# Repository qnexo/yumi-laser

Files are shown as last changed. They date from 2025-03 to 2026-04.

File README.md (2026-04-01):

<div align="center">

# Yumi Laser - Documentation Complète

&nbsp;
&nbsp;
&nbsp;
&nbsp;
&nbsp;

&nbsp;
&nbsp;
&nbsp;


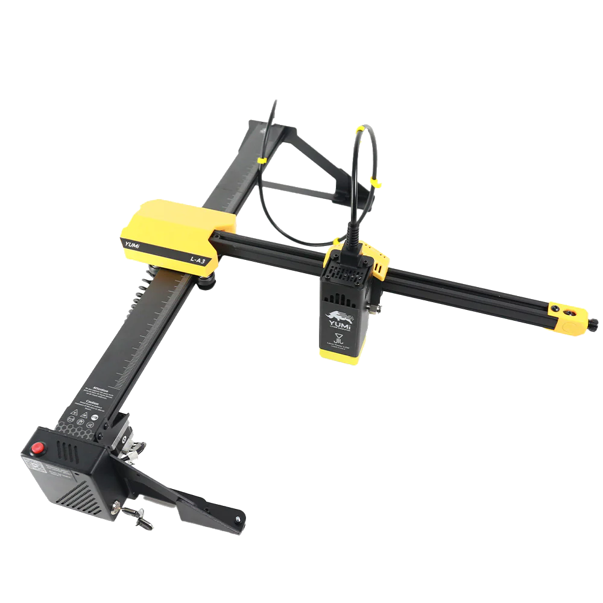
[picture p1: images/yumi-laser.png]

</div>

Bienvenue dans **le dépôt de référence pour modifier, améliorer et dompter le YUMI L-A**.  
Tu veux flasher un firmware propre, ajouter des capteurs de fin de course, activer le Wi-Fi sans écran, ou même modéliser des pièces pour ta machine ? 

T’es au bon endroit.

---

## 🚀 Objectif du projet

Ce dépôt regroupe **tout le nécessaire pour transformer ton YUMI L-A2** en une machine stable, modulaire et digne de projets sérieux.  
On parle ici de modifications concrètes testées IRL, pas de théories de forum.

---

## 📚 Sommaire
- [🛠️ Installation et Montage](https://github.com/qnexo/yumi-laser/blob/main/docs/yumi-laser-l-a4-a3-montage.pdf)
- [🚀 Firmware](#firmware)
- [📶 Configuration WiFi](#configuration-wifi)
- [📐 Logiciel LightBurn](https://lightburnsoftware.com/)
- [⚠️ Consignes de sécurité](#consignes-de-sécurité)
- [🛎️ Assistance et support](#assistance-et-support)
- [📜 Licence](#licence)

---

## 🧰 Contenu du dépôt

📁 firmware/ → Firmware GRBL modifié (capteurs, Wi-Fi, configs YUMI)

📁 hardware/ → STL/STEP, plans de montage, upgrades mécaniques

📁 docs/ → Fiches techniques et manuels PDF

📁 modifications/ → Étapes pas-à-pas pour les hacks (photos, branchements, etc.)

📁 tools/ → Scripts et utilitaires de flash/test

---

## 🛠️ Modifications principales

- ✅ Activation des **capteurs de fin de course**
- ✅ Activation du **Wi-Fi sans écran**
- ✅ Modification de la configuration GRBL pour laser YUMI
- ✅ Intégration de pièces imprimables (ventilateurs, support module, etc.)
- 🚧 [À venir] Ajout d’un relais de sécurité / arrêt d’urgence

---

## ⚙️ Installer le firmware

> 🔥 **Important** : Sauvegarde ton firmware d’origine si tu veux pouvoir revenir en arrière.

1. Branche ton YUMI via USB
2. Ouvre `tools/flasher.bat` *(ou utilise `avrdude` si tu préfères la ligne de commande)*
3. Flash le fichier `.hex` adapté à ta config depuis `firmware/`
4. Redémarre, connecte avec un terminal série (115200 baud)
5. Tape `$$` pour vérifier les réglages

---

## 🔌 Branchement des capteurs (Endstops)

**Type** : capteur mécanique Normally Open (NO)  
**Connexion** :
- X min → pin D9
- Y min → pin D10  
(Peut varier selon le modèle de carte – voir `docs/yumi-board-pinout.pdf`)

📸 *Voir photos dans `modifications/endstop-photos/`*

---

## 📷 Aperçus

YUMI Modifié  
*Vue avant avec support capteurs et module laser 10W*

---

## 📬 Contact & communauté

👉 Groupe WhatsApp : [**lien à insérer**]  
📧 Contact : qnexo.dev@gmail.com *(ou autre mail/profil si tu préfères)*

---

## ❤️ Contribuer

Les PR sont bienvenues. Merci de :
- Forker ce dépôt
- Travailler sur une branche dédiée
- Proposer une modif claire avec explication

---

## 🧠 À faire (Roadmap)

- [ ] Ajout d’un support écran TFT
- [ ] Ajout d’un système d’extraction d’air imprimable
- [ ] Création d’un profil LightBurn optimisé
- [ ] Documentation FR/EN parallèle

---

**Hack the machine. Dompte la lumière. 🔥**

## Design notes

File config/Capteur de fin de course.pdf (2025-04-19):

# Capteur de fin de course

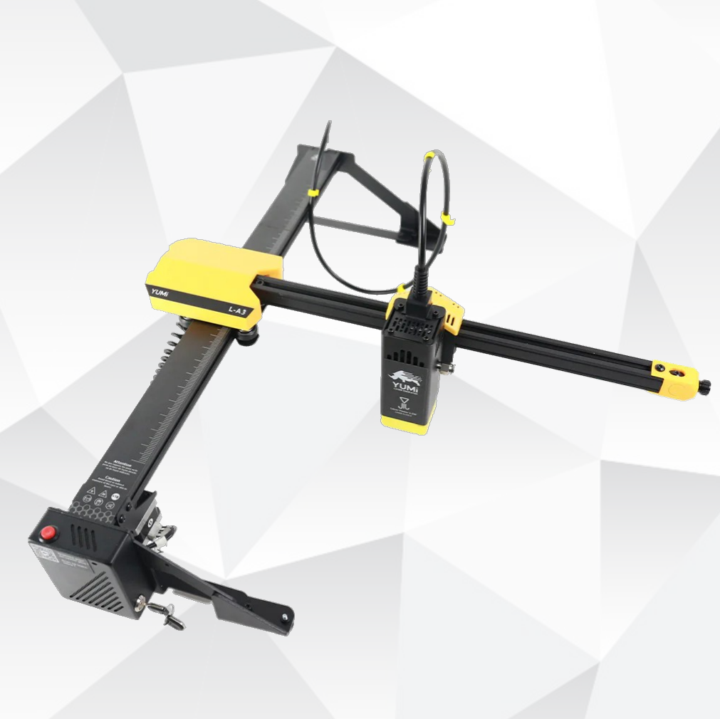
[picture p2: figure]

### Sommaire

1. Présentation du projet.
2. Matériel nécessaire.
3. Installation physique des capteurs.
4. Paramétrage dans LightBurn.
5. Réglages GRBL (copier-coller).
6. Vérification et tests.
7. Problèmes fréquents et solutions.
8. Notes personnelles.

### 1. Présentation du projet

L'ajout de capteurs permet de définir une origine fiable. Cela permet de bénéficier de la fonction Autoguider et d’éviter les dépassements de zone de travail.

### 2. Matériel nécessaire

- Laser Yumi L-A4/3/2
- Capteurs NO (normalement ouverts)
- Fils Dupont / connecteurs
- Logiciel LightBurn
- Pour ce montage, nous allons utiliser des capteurs GTIWUNG à butée mécanique, avec câble inclus.
On peut les trouver sur Amazon pour environ 9 €.
- N'oubliez pas de télécharger les fichiers STL pour les supports des capteurs.
Nous avons également d'autres modèles de fichiers STL, que ce soit à clips ou à visser, selon vos préférences.

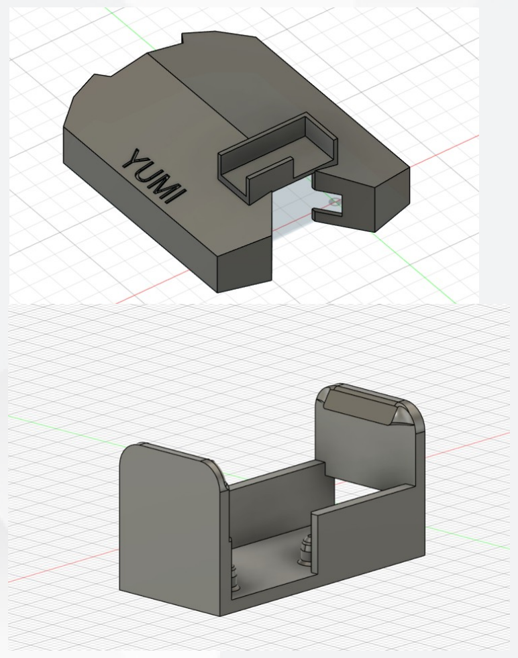
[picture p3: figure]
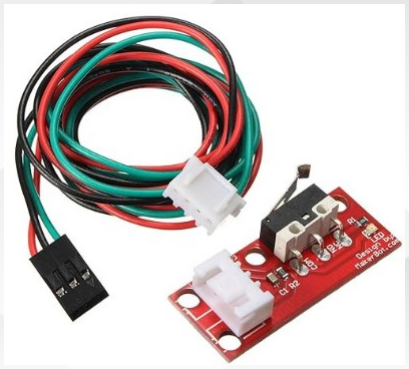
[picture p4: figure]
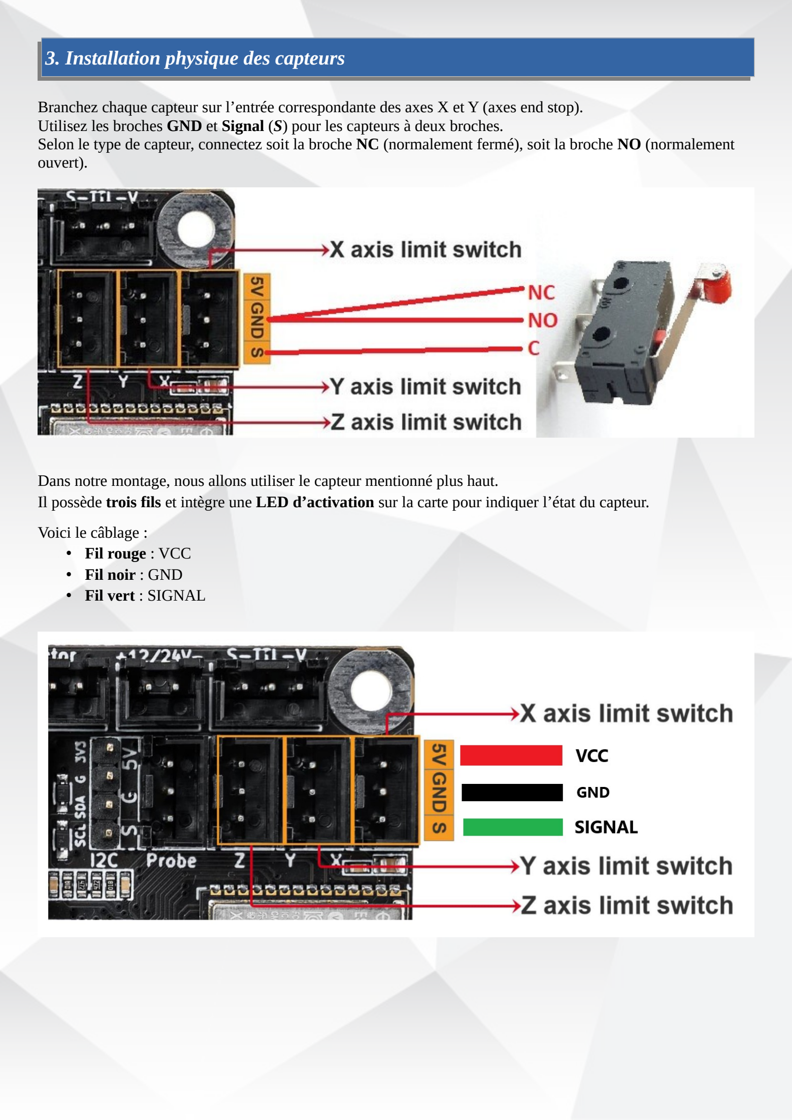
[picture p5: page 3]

### 3. Installation physique des capteurs

Branchez chaque capteur sur l’entrée correspondante des axes X et Y (axes end stop).
Utilisez les broches GND et Signal (S) pour les capteurs à deux broches.
Selon le type de capteur, connectez soit la broche NC (normalement fermé), soit la broche NO (normalement ouvert).

Dans notre montage, nous allons utiliser le capteur mentionné plus haut.
Il possède trois fils et intègre une LED d’activation sur la carte pour indiquer l’état du capteur. Voici le câblage :
- Fil rouge : VCC
- Fil noir : GND
- Fil vert : SIGNAL

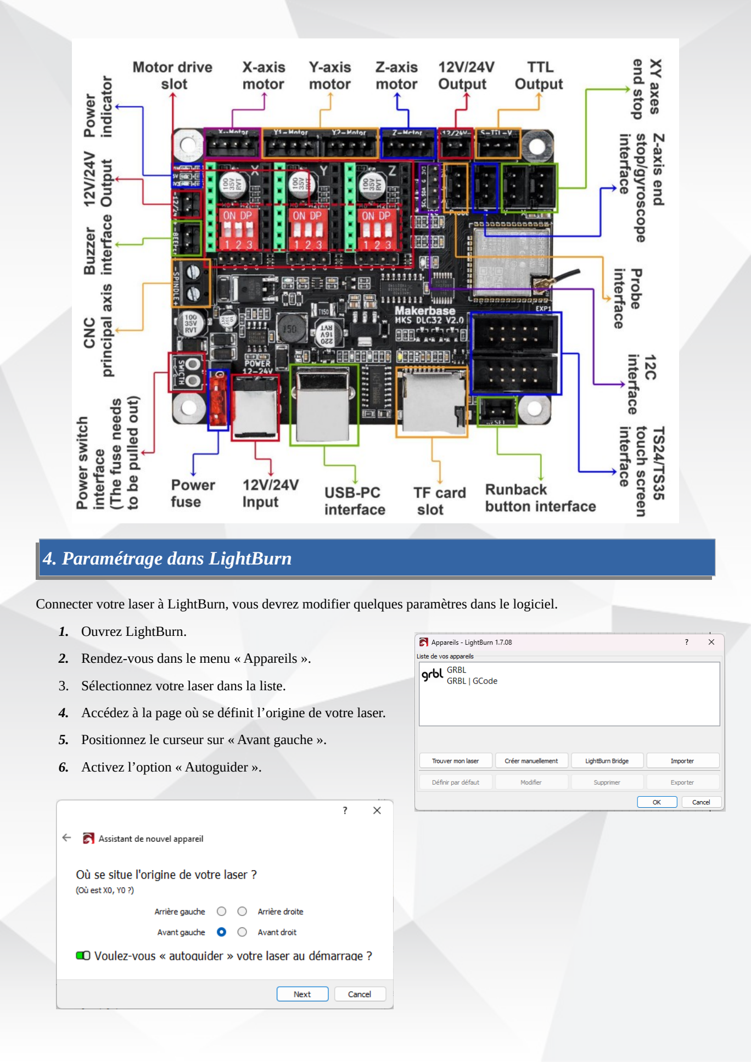
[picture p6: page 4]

### 4. Paramétrage dans LightBurn

Connecter votre laser à LightBurn, vous devrez modifier quelques paramètres dans le logiciel.

1. Ouvrez LightBurn.
2. Rendez-vous dans le menu « Appareils ».
3. Sélectionnez votre laser dans la liste.
4. Accédez à la page où se définit l’origine de votre laser.
5. Positionnez le curseur sur « Avant gauche ».
6. Activez l’option « Autoguider ».

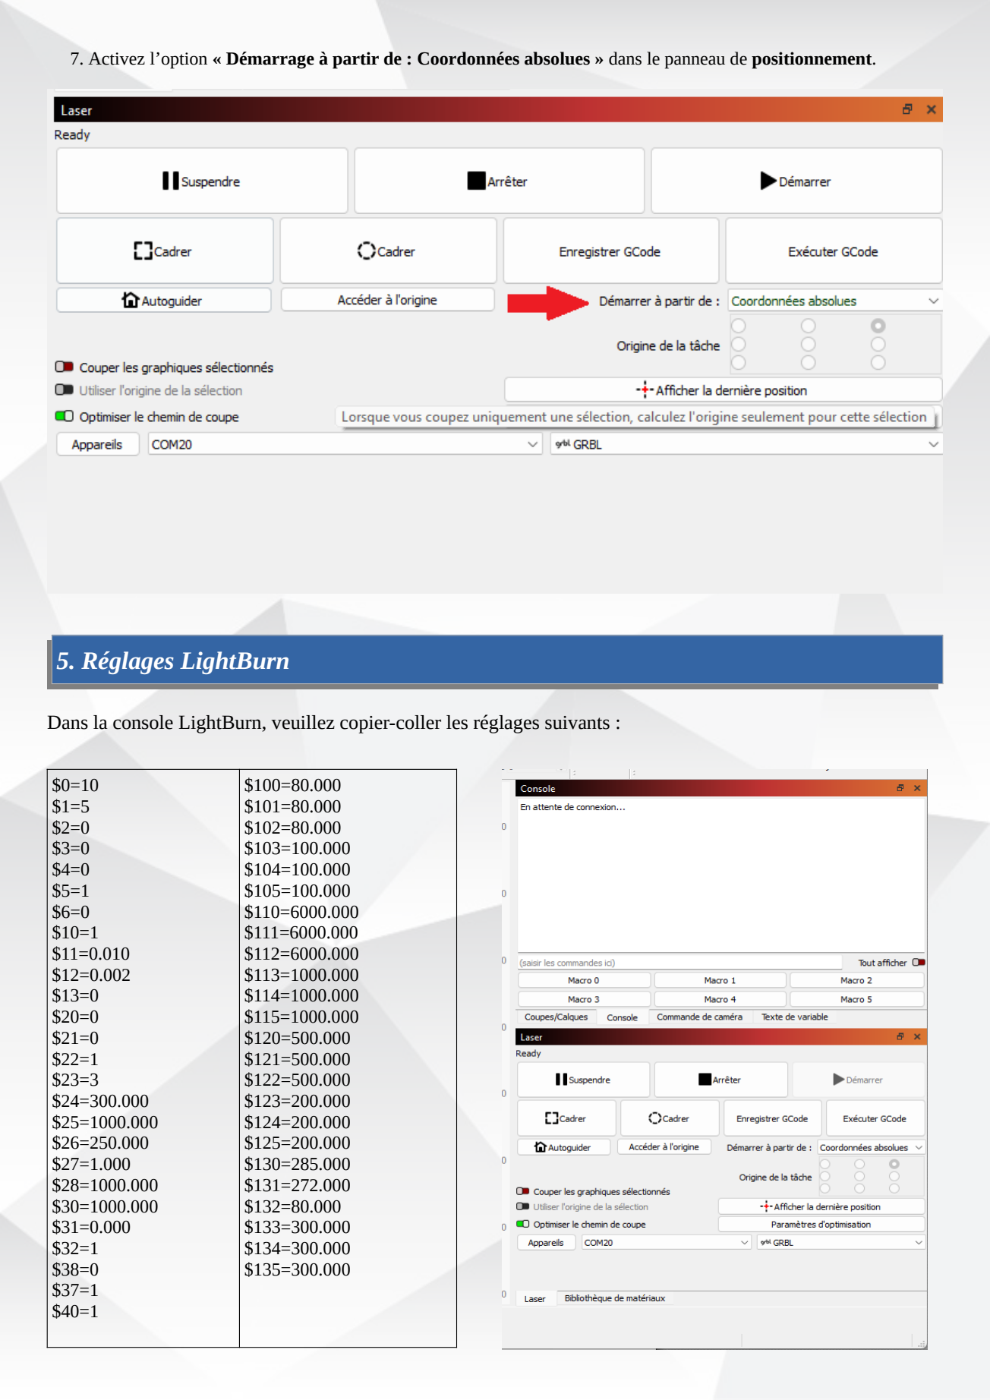
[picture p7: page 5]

7. Activez l’option « Démarrage à partir de : Coordonnées absolues » dans le panneau de positionnement.

### 5. Réglages LightBurn

Dans la console LightBurn, veuillez copier-coller les réglages suivants :

$0=10
$1=5
$2=0
$3=0
$4=0
$5=1
$6=0
$10=1
$11=0.010
$12=0.002
$13=0
$20=0
$21=0
$22=1
$23=3
$24=300.000
$25=1000.000
$26=250.000
$27=1.000
$28=1000.000
$30=1000.000
$31=0.000
$32=1
$38=0
$37=1
$40=1

$100=80.000
$101=80.000
$102=80.000
$103=100.000
$104=100.000
$105=100.000
$110=6000.000
$111=6000.000
$112=6000.000
$113=1000.000
$114=1000.000
$115=1000.000
$120=500.000
$121=500.000
$122=500.000
$123=200.000
$124=200.000
$125=200.000
$130=285.000
$131=272.000
$132=80.000
$133=300.000
$134=300.000
$135=300.000

### Paramètres – Détail et Fonction

Paramètre | Description | Valeur
$0 | Délai avant désactivation des moteurs | 10 ms
$1 | Délai de repos des moteurs | 5 ms
$2 | Inversion des signaux de pas | 0
$3 | Inversion des directions de moteur | 0
$4 | Inversion du signal d’activation des moteurs | 0
$5 | Inversion des signaux de fin de course | 1 (inversé)
$6 | Inversion du signal de la sonde (probe) | 0
$10 | Rapport d'état - masque de bits | 1
$11 | Déviation de jonction (fluidité des virages) | 0.010 mm
$12 | Tolérance des arcs (précision) | 0.002 mm
$13 | Unités en pouces (0 = mm, 1 = pouces) | 0 (mm)
$20 | Limites logicielles activées | 0 (désactivé)
$21 | Limites matérielles activées | 0 (désactivé)
$22 | Cycle de référencement (homing) activé | 1 (activé)
$23 | Inversion des directions du homing | 3
$24 | Vitesse de recherche du homing | 300 mm/min
$25 | Vitesse d’approche du homing | 1000 mm/min
$26 | Temps de rebond pour homing | 250 ms
$27 | Retrait après homing | 1 mm
$28 | Vitesse de retour G28 | 1000 mm/min
$30 | Vitesse maximale de la broche (ou laser) | 1000
$31 | Vitesse minimale de la broche (ou laser) | 0
$32 | Mode laser activé | 1 (activé)
$38 | Sonde activée | 0 (désactivé)
$37 | Accessoires activés | 1 (activé)
$40 | Désactivation automatique des moteurs | 1 (activé)
$100 | Pas/mm pour l’axe X | 80
$101 | Pas/mm pour l’axe Y | 80
$102 | Pas/mm pour l’axe Z | 80
$103 | Pas/mm pour l’axe A | 100
$104 | Pas/mm pour l’axe B | 100
$105 | Pas/mm pour l’axe C | 100
$110 | Vitesse max de l’axe X | 6000 mm/min
$111 | Vitesse max de l’axe Y | 6000 mm/min
$112 | Vitesse max de l’axe Z | 6000 mm/min

$113 | Vitesse max de l’axe A | 1000 mm/min
$114 | Vitesse max de l’axe B | 1000 mm/min
$115 | Vitesse max de l’axe C | 1000 mm/min
$120 | Accélération de l’axe X | 500 mm/s²
$121 | Accélération de l’axe Y | 500 mm/s²
$122 | Accélération de l’axe Z | 500 mm/s²
$123 | Accélération de l’axe A | 200 mm/s²
$124 | Accélération de l’axe B | 200 mm/s²
$125 | Accélération de l’axe C | 200 mm/s²
$130 | Course maximale de l’axe X | 285 mm
$131 | Course maximale de l’axe Y | 272 mm
$132 | Course maximale de l’axe Z | 80 mm
$133 | Course maximale de l’axe A | 300 mm
$134 | Course maximale de l’axe B | 300 mm
$135 | Course maximale de l’axe C | 300 mm

### 6. Vérification et tests

1. Connecter le laser via USB.
2. L’autoguidage doit se faire automatiquement.
3. Si ce n’est pas le cas, veuillez le faire manuellement en cliquant sur « Autoguider ».
4. Observer le comportement : arrêt correct sur les capteurs.
5. Corriger le placement du capteur si les fins de course ne réagissent pas.

### 7. Problèmes fréquents et solutions

Problème | Symptôme | Cause probable | Solution
Capteur ne réagit pas. | Laser ne s'arrête pas contrôle le capteur | Branchement incorrect. Capteur défectueux. | Vérifier câblage GND et S. Remplacement capteur NO.
Pas de mouvement Autoguider | Rien ne se passe | $22=1 non actif | Activer $22=1 et vérifier LED capteur
Origine incorrecte | Se place en haut | $23 incorrect | Mettre $23=1
LED toujours allumée | Toujours actif | Capteur défectueux ou NC | Tester en NO ou changer capteur
Erreur GRBL | Pas de connexion | Port ou vitesse incorrecte | Changement de port. Remplacement du câble USB.
Câblage chauffe | Reste machine | Court-circuit | Vérifier polarité et isoler câbles

Problème | Symptôme | Cause probable | Solution
Gravure faible ou inégale | Le laser grave faiblement ou par à-coups | Mauvaise mise au point ou lentille sale | Nettoyer la lentille, refaire la mise au point
Laser ne s’allume pas | Aucune émission laser pendant la gravure carte-mère allumé | Alimentation, mauvais câblage PWM ou $32=0 | Vérifier câblage, tester en manuel (M3 S100) et vérifier $$ voir $32 sur 1
Décalage des gravures | Le dessin est décalé ou en escalier | Poulie desserrée, courroie lâche, vitesse trop élevée | Resserrer, ajuster la tension des courroies, réduire la vitesse
Gravure en miroir | L’image est inversée | Origine mal définie, $3 mal configuré | Essayer différentes valeurs de $3 (inversion de directions moteurs)
Le Autoguider ne fonctionne pas | L’axe se déplace dans le mauvais sen | Mauvais sens moteur ou mauvais branchement capteur | Inverser sens moteur via $3, vérifier connexion des capteurs
L’axe cogne ou vibre | Mouvement irrégulier ou bruit anormal | Tension moteur incorrecte, mauvaise configuration | Vérifier les pilotes, ajuster le courant, vérifier le micro-stepping
Job s’arrête au milieu | Gravure arrêtée sans message d’erreur | Perte de communication, mauvaise alimentation | Changer câble USB, utiliser alimentation stable, désactiver l’économiseur USB
Assist toujours active | Pompe tourne en continu | Branchée en direct ou mauvaise config pin | Vérifier branchement, désactiver Air Assist dans LightBurn, envoyer M9
Carte ne démarre pas du tout | Aucun signe de vie, même pas d’écran | Alimentation, Contacteur à clé HS ou inactif | Remplacer le contacteur ou le retirer (pont direct) Vérifier alim 12/24V
Gravure se fait au mauvais endroit | Décalage par rapport au visuel dans LightBurn | Origine mal placée, mode de départ incorrect | Vérifier position d’origine et mode Start from (User origin, etc.)
Laser ne s’éteint pas après un job | Reste allumé à faible puissance | Mode laser mal géré ou M5 non envoyé | Ajouter M5 à la fin, vérifier $32=1 pour laser mode
Gravure irrégulière sur les bords | Bords flous ou trop puissants | Mauvais réglage d’accélération / vitesse | Réduire accélération ($120/$121) ou la vitesse
Le job s’exécute à l’envers | Gravure retournée horizontalement ou verticalement | Mauvaise configuration de $3 ou de l’origine | Tester les 4 combinaisons possibles de $3 (de 0 à 7) câble Y au mauvais endroit
Connexion instable via WiFi | Déconnexion fréquente ou lenteur | Mauvaise réception du WiFi | Réduire distance au routeur, privilégier wifi 2.5GHz stable, privilégier USB,
Gravure en “pointillés” | Le laser clignote ou ne reste pas constant | Mauvaise masse, mauvais câblage TTL ou problème GND | Vérifier GND commun entre laser et carte, resserrer connexions

### 8. Notes personnelles

Espace libre pour remarques et réglages spécifiques : _________________________________________________________________________________________ _________________________________________________________________________________________ _________________________________________________________________________________________ _________________________________________________________________________________________ _________________________________________________________________________________________ _________________________________________________________________________________________ _________________________________________________________________________________________ _________________________________________________________________________________________ _________________________________________________________________________________________ _________________________________________________________________________________________ _________________________________________________________________________________________ _________________________________________________________________________________________ _________________________________________________________________________________________ _________________________________________________________________________________________ _________________________________________________________________________________________ _________________________________________________________________________________________ _________________________________________________________________________________________ _________________________________________________________________________________________ _________________________________________________________________________________________ _________________________________________________________________________________________ _________________________________________________________________________________________ _________________________________________________________________________________________ _________________________________________________________________________________________ _________________________________________________________________________________________ _________________________________________________________________________________________ _________________________________________________________________________________________ _________________________________________________________________________________________ _________________________________________________________________________________________ _________________________________________________________________________________________ _________________________________________________________________________________________ _________________________________________________________________________________________ _________________________________________________________________________________________ _________________________________________________________________________________________ _________________________________________________________________________________________ _________________________________________________________________________________________ _________________________________________________________________________________________ _________________________________________________________________________________________ _________________________________________________________________________________________ _________________________________________________________________________________________ _________________________________________________________________________________________ _________________________________________________________________________________________ _________________________________________________________________________________________ _________________________________________________________________________________________ _________________________________________________________________________________________

## 📘 À propos de ce PDF

Ce document a été entièrement réalisé par mes soins, en m’appuyant sur la documentation officielle de LightBurn et de Makerbase.
🙏 Un grand merci à Cupidon3D pour son aide précieuse tout au long de la configuration, ainsi que pour la mise à disposition de ses fichiers STL disponible sur le github.

🔗 Sources utiles :

📌 Documentation LightBurn (version 1.7) :
LightBurn PDF
📌 Documentation Makerbase (MKS DLC32) : Makerbase GitHub

### ⚠️ Clause de non-responsabilité

Ce document est fourni à titre informatif.
Toute modification apportée à votre matériel ou logiciel suite à ce tutoriel est réalisée à vos propres risques.
Ni l’auteur de ce document, ni les marques citées (Yumi, Makerbase, LightBurn) ne peuvent être tenus responsables des dommages matériels ou erreurs de configuration causés par une mauvaise manipulation ou un usage inadapté.

Document réalisé pour les utilisateurs du laser YUMI L-A4/3/2 ou de cartes MKS DLC32 V2,1 ✍️Par qnexo / coco

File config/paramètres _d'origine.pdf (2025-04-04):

## Paramètres de Configuration - MKS DLC32

Paramètre | Valeur | Description
DLC_TEST | 0 | Mode d'utilisation normal (0), pas le mode test (1)
$0 | 10 | Délai d'inactivité avant désactivation moteur (ms)
$1 | 5 | Temps de maintien moteur après désactivation
$2 | 0 | Inversion direction des axes (bitmask)
$3 | 0 | Sens des axes (bitmask pour homing)
$4 | 0 | Pas/inversion pour drivers
$5 | 1 | Inversion signal de fin de course X
$6 | 0 | Inversion du signal de la sonde
$10 | 1 | Rapports de position machine uniquement
$11 | 0.010 | Précision du planage (mm)
$12 | 0.002 | Précision des arcs
$13 | 0 | Unités (0 = mm, 1 = pouces)
$20 | 0 | Limite logicielle désactivée
$21 | 0 | Fins de course désactivées
$22 | 0 | Homing désactivé
$23 | 1 | Direction du homing (X inversé, Y normal)
$24 | 300.000 | Vitesse lente du homing (mm/min)
$25 | 1000.000 | Vitesse rapide du homing (mm/min)
$26 | 250.000 | Délais de rebond capteurs (debounce)
$27 | 1.000 | Retrait après déclenchement capteur
$28 | 1000.000 | Paramètre interne (MKS)
$30 | 1000.000 | Puissance maximale PWM du laser
$31 | 0.000 | Puissance minimale PWM du laser
$32 | 1 | Mode laser activé

$37 | 1 | Retour à lorigine après tâche
$38 | 1 | Détection de fin de course active (MKS)
$40 | 0 | Mode CNC activé
$100 | 80.000 | Steps/mm axe X
$101 | 80.000 | Steps/mm axe Y
$102 | 80.000 | Steps/mm axe Z
$103 | 100.000 | Steps/mm axe U
$104 | 100.000 | Steps/mm axe V
$105 | 100.000 | Steps/mm axe W
$110 | 6000.000 | Vitesse max axe X (mm/min)
$111 | 6000.000 | Vitesse max axe Y
$112 | 6000.000 | Vitesse max axe Z
$113 | 1000.000 | Vitesse max axe U
$114 | 1000.000 | Vitesse max axe V
$115 | 1000.000 | Vitesse max axe W
$120 | 500.000 | Accélération axe X (mm/s²)
$121 | 500.000 | Accélération axe Y
$122 | 500.000 | Accélération axe Z
$123 | 200.000 | Accélération axe U
$124 | 200.000 | Accélération axe V
$125 | 200.000 | Accélération axe W
$130 | 285.000 | Taille axe X (mm)
$131 | 272.000 | Taille axe Y
$132 | 80.000 | Taille axe Z
$133 | 300.000 | Taille axe U
$134 | 300.000 | Taille axe V

$135 | 300.000 | Taille axe W
[ESP110] | STA | Mode station activé (connexion à un réseau existant)
[ESP131] | 8080 | Port réseau utilisé pour la connexion TCP/IP
[ESP100] | SSID | Nom du réseau WiFi (SSID) utilisé en mode STA
[ESP101] | Password | Mot de passe WiFi utilisé pour la connexion STA

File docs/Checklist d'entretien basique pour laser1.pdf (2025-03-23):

## 🛠️ Checklist d'entretien basique pour laser :

✅ Avant chaque utilisation :
- Inspection visuelle rapide :
- Vérifie l'état des câbles et des connexions.
- Vérifie que les lentilles du laser soient propres.
- Nettoyage des lentilles :
- Utilise un chiffon microfibre et de l'alcool isopropylique.
- Nettoie délicatement pour éliminer poussière et fumée.

✅ Toutes les 10 à 20 heures d'utilisation :
- Nettoyage approfondi du module laser :
- Retire la poussière accumulée à l'aide d'une soufflette à air comprimé.
- Contrôle des axes et rails :
- Nettoie les rails avec un chiffon sec.
- Vérifie qu'il n'y a aucun résidu de matière sur les axes.
- Lubrification des rails et roulements :
- Applique une fine couche de lubrifiant à base de silicone sur les rails linéaires et les roulements pour garantir un mouvement fluide.
- Contrôle des courroies :
- Vérifie la tension des courroies, ajuste-les si nécessaire (tension modérée, ni trop serrées ni lâches).

1/2

✅ Tous les 3 mois (ou environ 50 heures d'utilisation) :
- Vérification approfondie des câbles et connecteurs :
- Inspecte soigneusement les connexions électriques.
- Remplace tout câble abîmé ou suspect.
- Inspection et nettoyage de la carte électronique (MKS DLC32) :
- Éteins et débranche le laser.
- Inspecte visuellement la carte pour détecter tout signe d'usure, de court-circuit ou poussière excessive.
- Nettoie doucement avec une soufflette ou un pinceau antistatique.

✅ Tous les 6 mois (ou 100 heures d'utilisation) :
- Contrôle général de sécurité :
- Vérifie l'intégrité physique du châssis et des protections mécaniques.
- Remplace tout élément endommagé pour garantir la sécurité d'utilisation.
- Mise à jour éventuelle du firmware :
- Vérifie si une mise à jour officielle du firmware est disponible.
- Fais une sauvegarde de ta configuration actuelle avant toute mise à jour.

## Précautions générales à suivre :

- Éteins toujours le laser avant tout entretien.
- Évite tout contact direct avec la lentille du laser à mains nues.
- Garde un environnement de travail propre et organisé.
- Utilise toujours des équipements de protection individuelle (lunettes, gants).

2/2

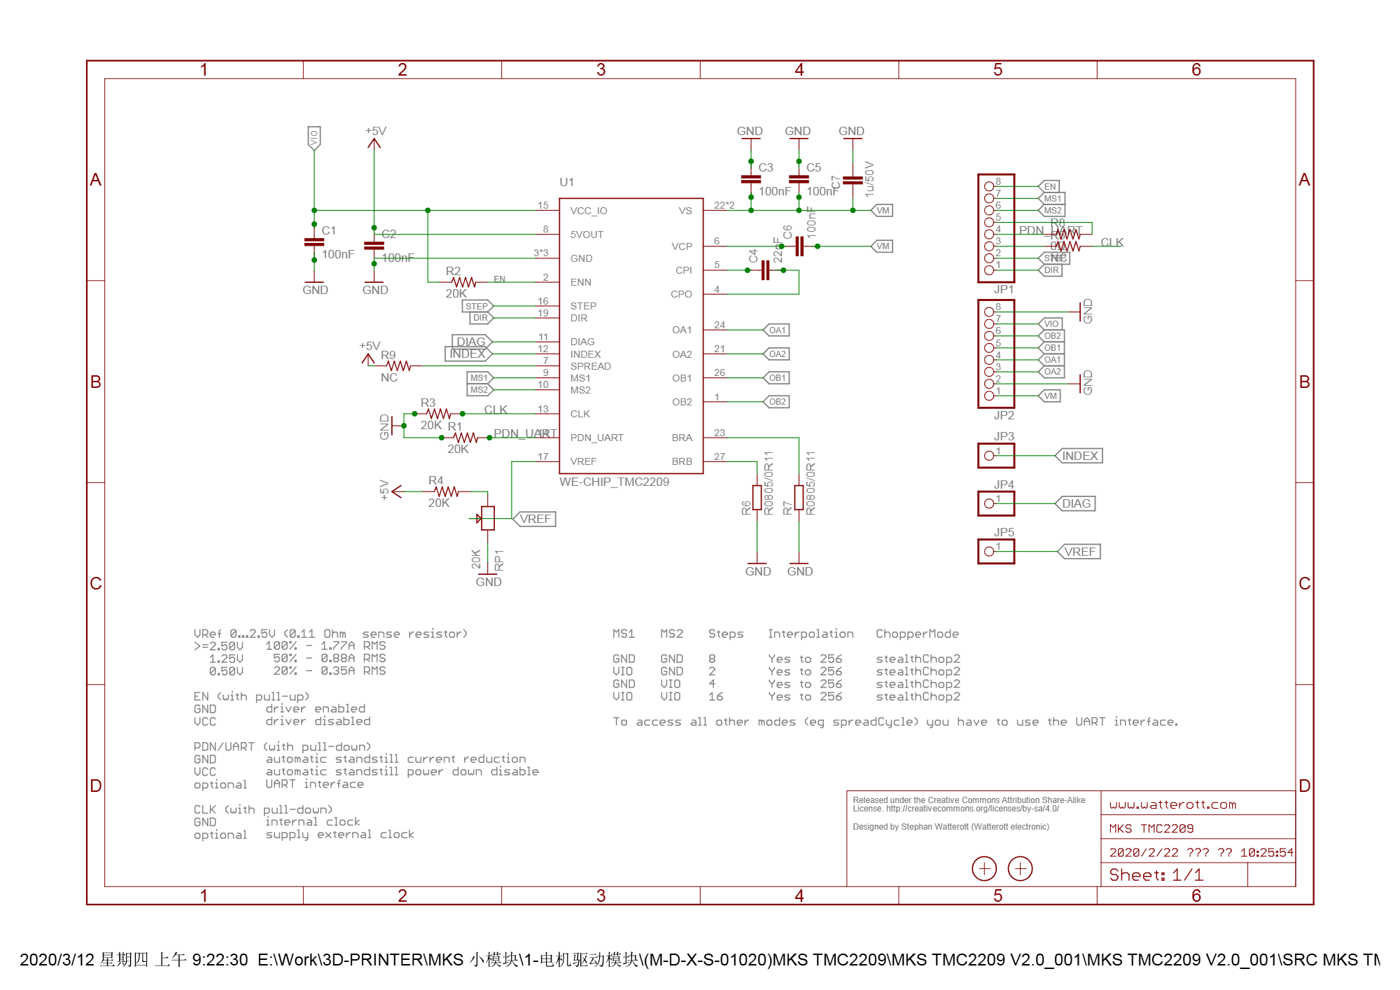
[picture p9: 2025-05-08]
images/tmc.png

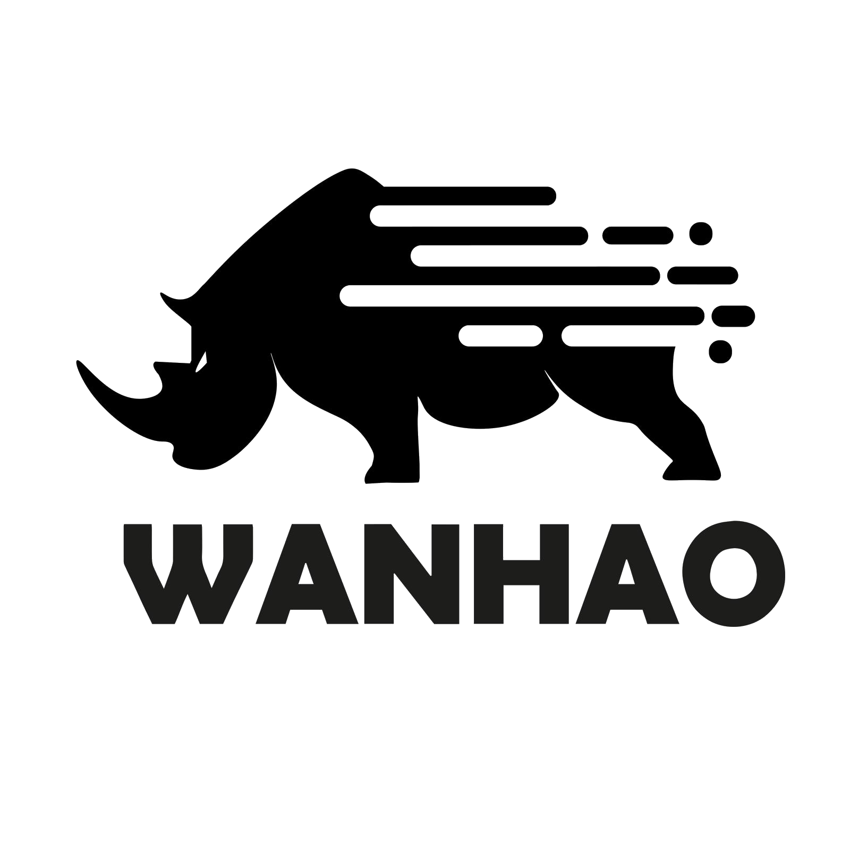
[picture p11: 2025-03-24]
images/wanhao.png

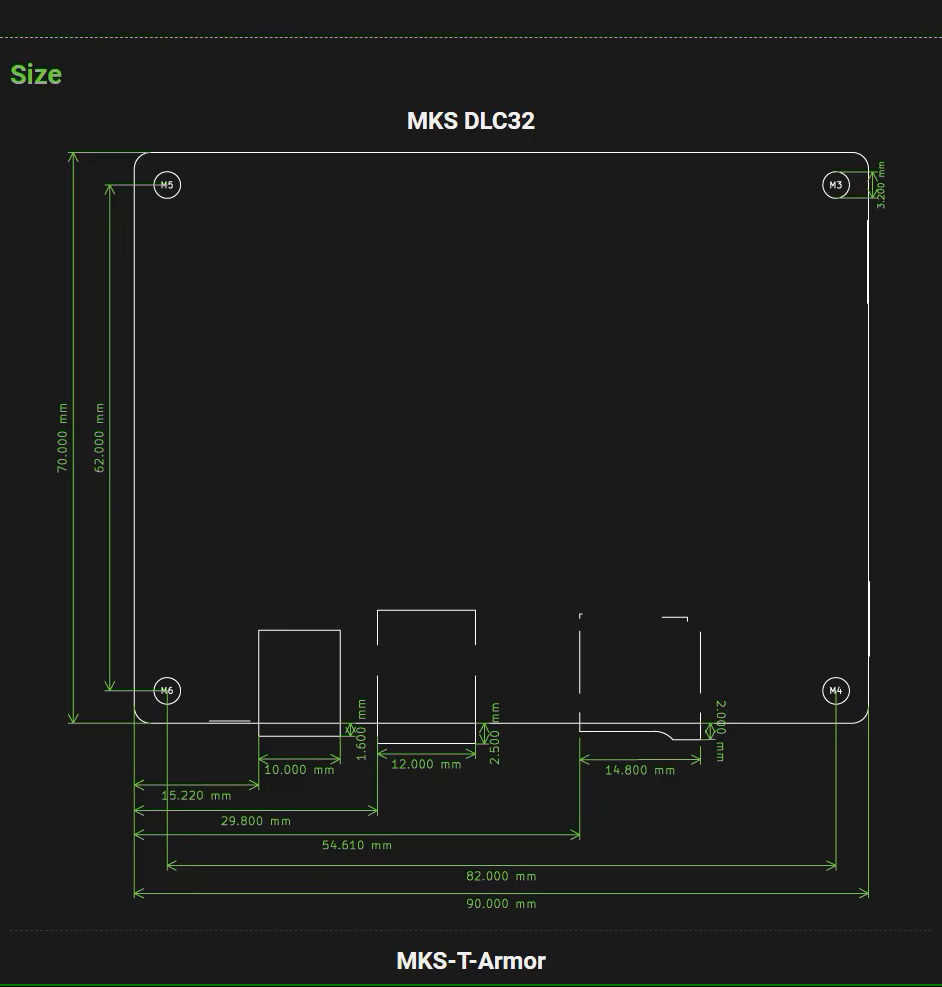
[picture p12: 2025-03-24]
images/S42874fc903dd443fb5ebef1ba6c39d80R.png

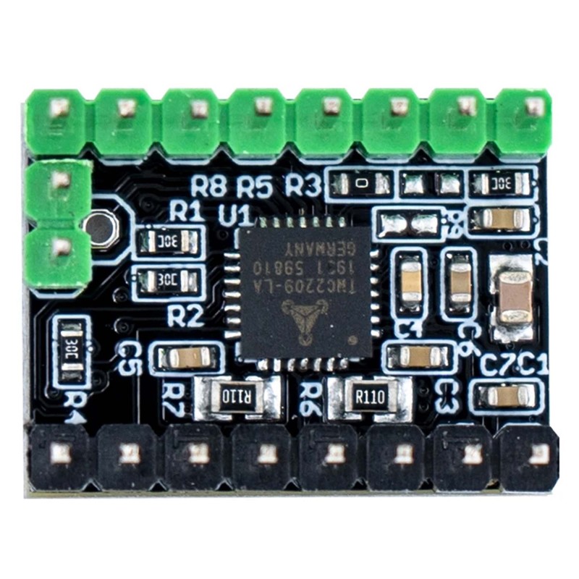
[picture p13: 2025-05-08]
images/driver-pilote-de-moteur-pas-a-pas-tmc2209.jpg

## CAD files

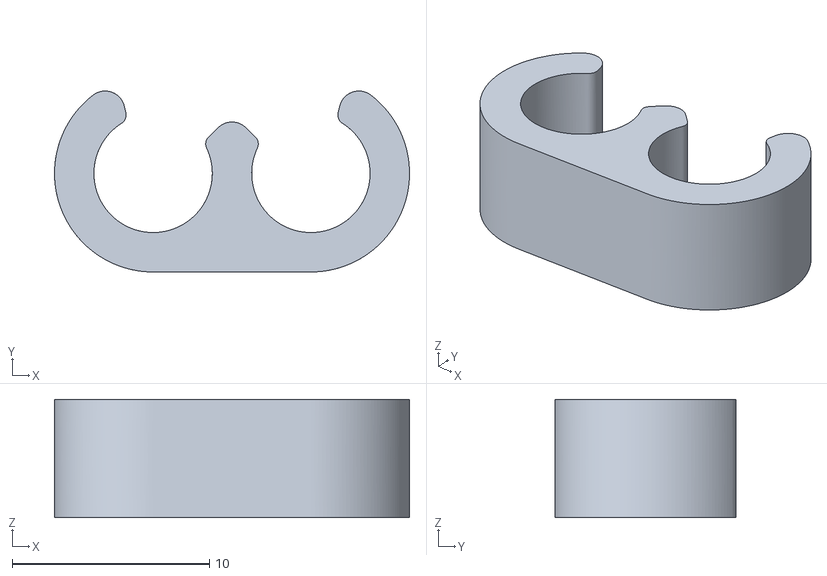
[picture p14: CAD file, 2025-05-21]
stl/clipse d'origine.stl
18.0 x 9.18 x 6.00

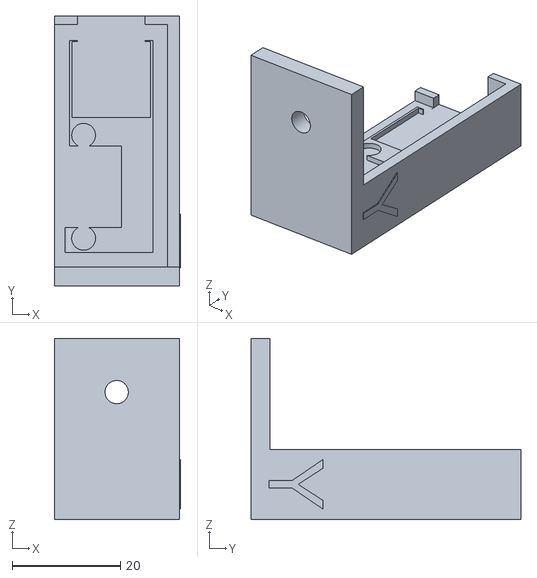
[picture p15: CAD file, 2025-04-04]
stl/modélisation de Cupidon3d support capteur à vis/support Y.stl
23.3 x 49.8 x 33.4

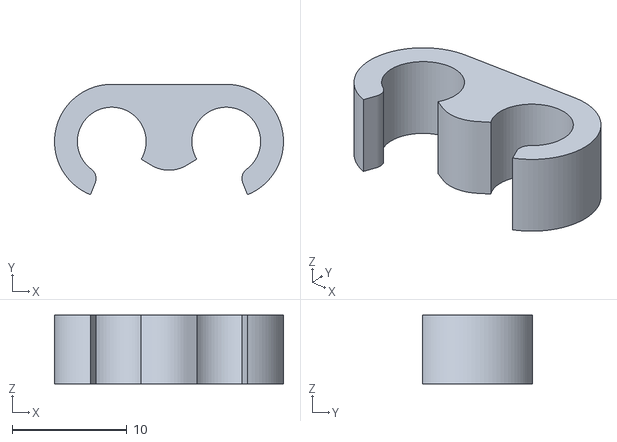
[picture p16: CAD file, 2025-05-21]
stl/clip cable.stl
20.0 x 9.64 x 6.00

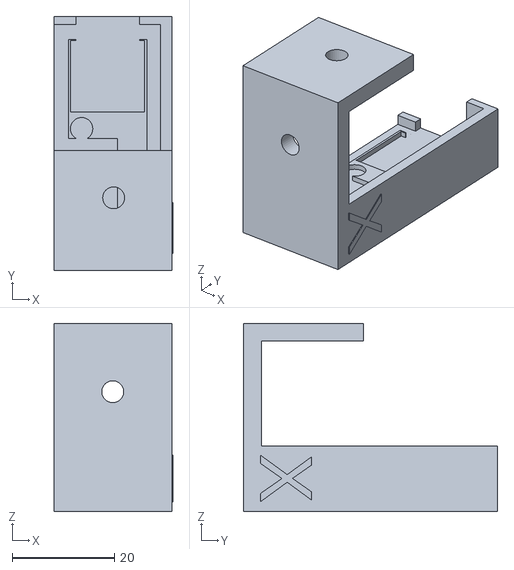
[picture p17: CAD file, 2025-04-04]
stl/modélisation de Cupidon3d support capteur à vis/support Y avec retour.stl
23.3 x 49.8 x 36.9

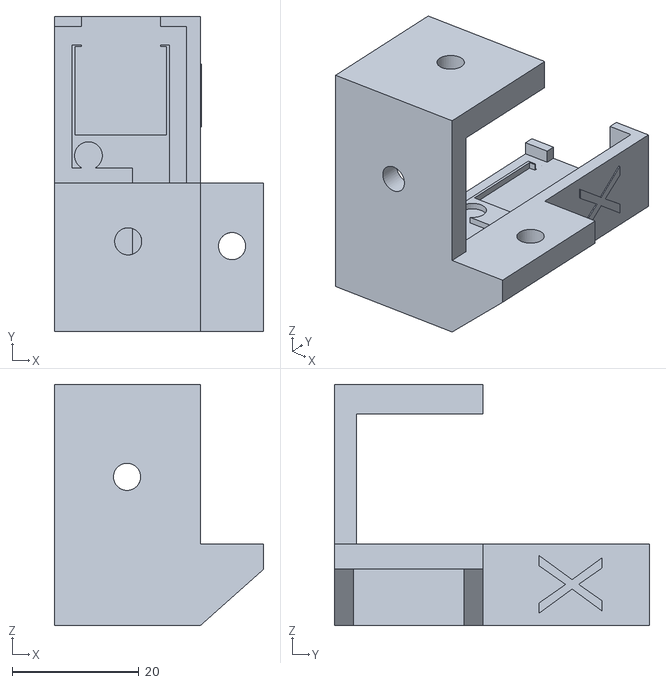
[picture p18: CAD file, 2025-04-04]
stl/modélisation de Cupidon3d support capteur à vis/support X.stl
33.1 x 49.8 x 38.1

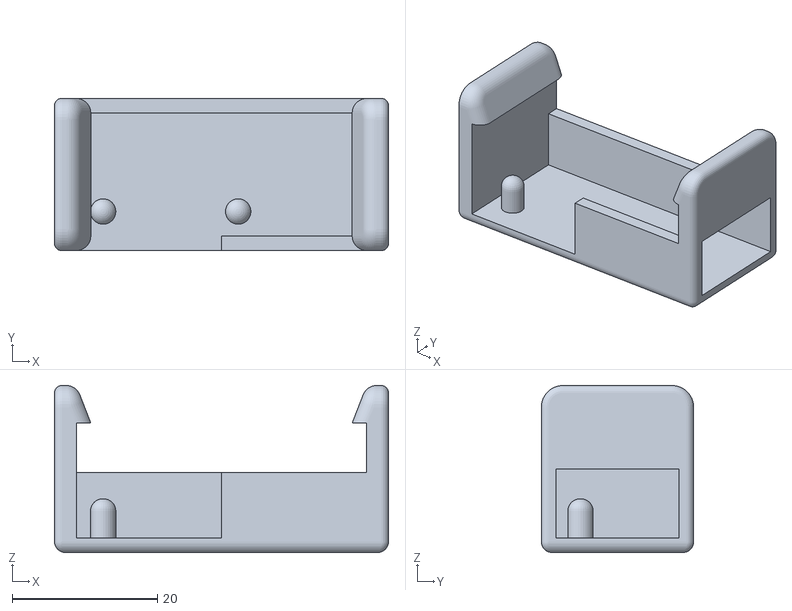
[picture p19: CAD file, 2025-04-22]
stl/support à clips Y.stl
46.0 x 21.0 x 23.0

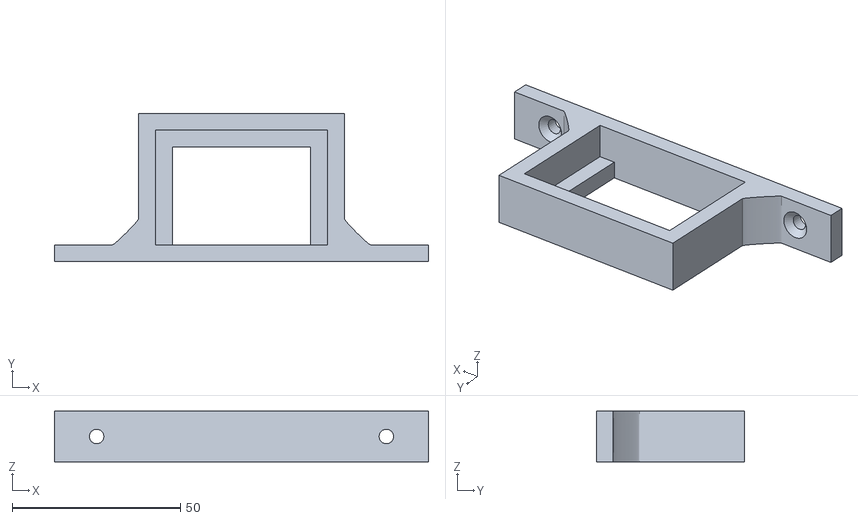
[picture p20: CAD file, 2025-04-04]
stl/support tranfo laser.stl
111.0 x 44.0 x 15.0

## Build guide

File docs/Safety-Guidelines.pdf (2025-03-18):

Consignes de Sécurité - Yumi Laser

Sécurité avant tout !
L'utilisation du graveur laser Yumi L-A2/A3/A4 nécessite le respect strict des consignes de sécurité. Ce document détaille les risques, les équipements de protection nécessaires et les bonnes pratiques pour une utilisation en toute sécurité.

### 1. Risques liés au laser

⚠ Laser Classe 4 : Dangers et Précautions
- Les lasers classe 4 peuvent causer des brûlures graves et des lésions oculaires irréversibles.
- L’exposition directe au faisceau ou aux réflexions diffuses peut entraîner une cécité immédiate.
- Le laser peut enflammer certains matériaux (bois, papier, textile, etc.).

🛡 2. Équipements de Protection Obligatoires

Lunettes de protection adaptées
- Utiliser des lunettes certifiées pour la longueur d’onde du laser.
- Ne pas utiliser les lunettes fournies avec certains modèles, car elles peuvent ne pas être conformes.
- Lien pour des lunettes conformes : Exemple de fournisseur (https://www.apinex.com/det/lunettes-protection-laser.html)

•
🌬 Ventilation et extraction des fumées
- La gravure/découpe produit des vapeurs toxiques et des particules fines.
- Travailler dans un espace bien ventilé ou utiliser un système d’extraction des fumées.

•
Extincteur à proximité
- Un risque d’incendie existe avec les matériaux combustibles.
- Avoir un extincteur CO2 ou Halotron à proximité immédiate.

### 3. Matériaux Interdits

Certains matériaux dégagent des gaz toxiques lorsqu'ils sont gravés/découpés. Ne jamais utiliser :

PVC / Vinyle → Dégage du chlore et de l’acide chlorhydrique toxiques

Polycarbonate / Lexan → Dégrade la qualité du laser et produit des fumées dangereuses

Fibres de carbone → Détruit l’optique du laser

Matières contenant du plomb ou du cadmium → Extrêmement toxiques

### 4. Bonnes Pratiques d’Utilisation

Avant d’allumer le laser

✔ Vérifier que le matériel est bien fixé et stable.

✔ Porter ses lunettes de protection avant toute manipulation.

✔ S’assurer qu’aucun objet réfléchissant (métal poli, verre) n’est dans la zone de gravure.

✔ Ne jamais utiliser le laser près d’un produit inflammable.

✔ Température maximale conseillée : 30°C. Ne pas utiliser au-delà.

Pendant l’utilisation

✔ Ne jamais quitter le laser sans surveillance.

✔ Rester à proximité immédiate pour intervenir en cas de problème.

✔ Vérifier régulièrement que la ventilation fonctionne.
⏹ Après utilisation

✔ Éteindre complètement le laser et débrancher l'alimentation.

✔ Nettoyer la zone de travail pour éviter l’accumulation de poussières inflammables.

✔ Entretenir le laser :
- Nettoyage des lentilles avec un chiffon microfibre et un produit adapté.
- Vérification des câbles et des connexions électriques.
- S’assurer qu’aucun résidu ne gêne le mouvement du laser.

✔ Laisser refroidir le laser avant toute manipulation.

### 5. En cas de problème

Que faire en cas d’incendie ?
1 Couper immédiatement l’alimentation électrique du laser.
2 Utiliser un extincteur adapté (CO2 ou Halotron, jamais d’eau !). 3 Évacuer la zone si nécessaire.

👁 Que faire après une exposition accidentelle au laser ?
- Symptômes possibles : vision floue, douleurs, sensation de brûlure.
- Ne pas attendre et consulter un ophtalmologue en urgence.
- Ne pas utiliser de collyres sans avis médical.

### 6. Respect des Règles de Sécurité

L’utilisation du Yumi Laser implique une responsabilité individuelle. Ces consignes doivent être respectées scrupuleusement pour éviter tout accident.

Ne jamais sous-estimer le danger d’un laser Classe 4.

Toujours privilégier la sécurité à la rapidité d’exécution.

Si vous avez un doute, demandez conseil à un professionnel.

Ce document peut être mis à jour en fonction des nouvelles recommandations de sécurité.

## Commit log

2025-03-18 Create DLC32 wiring manual.pdf
2025-03-23 Create Checklist d'entretien basique pour laser1.pdf
2025-03-23 Create installation et paramétrage des capteurs de fin de course.pdf
2025-03-24 Create paramètres de configuration d'origine.pdf
2025-04-04 Create capot x3.stl
    [capot x3.stl]
2025-04-04 Create capot y2.stl
    [capot y2.stl]
2025-04-04 Create capot y3.stl
    [capot y3.stl]
2025-04-04 Create support tranfo laser.stl
    [support tranfo laser.stl]
2025-04-19 Create Capteur de fin de course.pdf
2025-04-21 coco
    modification
    [support X.stl, support Y avec retour.stl, support Y.stl]
2025-04-22 Create support à clips Y.stl
    [support à clips Y.stl]
2025-05-21 up
    up
    [clip cable.stl, clipse d'origine.stl]
2026-02-01 Update 3mm poplar plywood engrave for 10w machines.lbrn

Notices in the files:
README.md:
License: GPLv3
